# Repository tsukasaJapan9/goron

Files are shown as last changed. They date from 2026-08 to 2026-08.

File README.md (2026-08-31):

# goron — 2軸クランク脚ロボット

胴体＋左右独立2脚（360°連続回転）で、起き上がり・移動・横転・ジャンプを
強化学習で獲得させるプロジェクト。MuJoCo でのシミュレーションと Sim2Real を前提とする。

参考: [poco](https://homemadegarbage.com/rl13)（2軸シリアルアーム型）。本機はシリアル
チェーンではなく **胴体＋左右独立脚のパラレル構造**で、脚が連続回転する点が異なる。
脚を矢状面で連続回転させる構成は [RHex](https://en.wikipedia.org/wiki/RHex) 系
（回転するCレッグ）の最小構成にあたる。

## 機体構成

```
        torso  (M5Stack + バッテリー, free joint)
       /                              \
   hip_left (hinge, axis = Y)   hip_right (hinge, axis = Y)
   360°連続回転                  360°連続回転
```

脚は胴体の左右（±Y）に取り付くが、**振れる向きは前後（矢状面）**。ヒンジ軸が
胴体の左右方向(Y)に平行なので、両脚がオールのように前後に回り続ける。

この選択が設計全体を規定する:

- 両脚を揃えて回すと**ピッチ**トルクが出る。起き上がりは横転ではなく
  **前転／後転（宙返り）**になる。
- 難易度を決める胴体寸法は `torso_width` ではなく **`torso_len` (X)**。
  胴体は前後の端（x = ±27 mm）を支点として越えていく必要がある。
- 左右のミラー関係が存在しない。両ヒップとも +Y 軸まわりに同じ向きに回るので、
  `ctrl = [+a, +a]` で同位相（ピッチ／ホップ）、`ctrl = [+a, -a]` で逆位相
  （ヨー／シザース）。
- ヒップは**胴体より外側**（`hip_y_gap`）に出す必要がある。そうしないと脚が
  胴体を通過できず360°回転が成立しない。`leg_clears_torso` で検査している。

## 実機構成

| 部品 | 型番 | 諸元 |
|---|---|---|
| サーボ×2 | Dynamixel **XL330-M288-T** | 288.4:1、停動 0.52 N·m / 無負荷 103 rpm (5V)、12bit絶対エンコーダ、18 g |
| コントローラ | **M5Stack Core** 系 | 54×54×16 mm、6軸IMU内蔵 |

合計約 151 g。サーボは **Extended Position Control Mode（±256回転）** で駆動する。
このモードだけが「360°連続回転」と「絶対角度フィードバック」を同時に成立させる。

### 設計上の落とし穴（実装で踏んだもの）

**XL330のケース厚(26 mm)は M5Stack(16 mm)より厚い。** サーボを胴体の中央高さに
付けると、ケースが腹面より 5 mm 下に突き出し、ロボットは腹ではなく**サーボケースの上に
乗って静止する**。この状態では「腹が接地」というゴール条件が原理的に達成できず、
ゴール到達可能なクランク角は 24通り中 2通りしかなかった。サーボを上面側
(`hip_z_frac=1.0`) に寄せると 19/24 に改善する。`servo_clears_belly` で検査し、
`train.py` は違反する設定を起動時に拒否する。

## ゴール姿勢の定義（パターンA:「伏せ」）

`SelfRight` タスクは次の3条件が `hold_steps`（既定 25 step = 0.5 s）連続で成立したら成功:

1. 胴体の上向き軸が鉛直から `prone_tilt`（既定 25°）以内
2. **胴体の箱が床に接触している**（脚やサーボで突っ張っているのではない）
3. 角速度 |ω| が `settle_omega`（既定 3.0 rad/s）未満

2番目の接触条件が本質的。これがないと「脚で突っ張って斜めに静止」が成功扱いになる。
1番目は「横倒し／エッジ立ち」を排除する。脚は連続回転するので、伏せるにはクランクを
上向きに畳む必要があり、自然に「脚をたたむ」動作が要求される。

## 観測と行動（実機で取れる量だけ）

観測 14次元 — すべて M5Stack の6軸IMU と XL330 の TTL フィードバックから得られる:

| index | 内容 | 実機での取得元 |
|---|---|---|
| 0:3 | 重力方向（胴体座標系） | IMU 姿勢フィルタ / 加速度計 |
| 3:6 | 角速度 (rad/s) | ジャイロ |
| 6:10 | 各クランク角の sin/cos | XL330 絶対エンコーダ |
| 10:12 | クランク角速度（正規化） | XL330 Present Velocity |
| 12:14 | サーボトルク（正規化） | XL330 Present Current |

クランク角を生の角度ではなく **sin/cos** で入れているのは、関節が回り続けるため。
生角度だと1周ごとに不連続になり、値も無限に増える。

意図的に**含めない**もの: 胴体の位置とヨー角。実機で測れないし、どのタスクにも不要。
ヨー・並進・1回転ぶんのラップに対する観測の不変性はテストで担保している。

行動 2次元 `[-1, 1]`: Extended Position 目標角の**増分**。行動が飽和したとき
ちょうどサーボの無負荷速度になるようスケールしてある。さらに目標角は実測角から
`max_lead`（既定 0.5 rad）以内に制限される — これがないと脚が引っかかったときに
目標角が無限に先走り（ワインドアップ）、復帰に数秒かかる。実機でも必要なガード。

制御周期 50 Hz（物理 500 Hz、`frame_skip=10`）。

## タスク

ハードウェアは固定で、目的だけ差し替える。`Task` が持つのは
`reset()` / `reward()` / `terminated()` の3つだけで、観測・サーボモデル・接触判定は
`GoronEnv` 側にある。

| タスク | 内容 | 状態 |
|---|---|---|
| `selfright` | 仰向け → 伏せ | 調整済み |
| `forward` | 進行方向へ移動（RHex的なパドリング） | 初版 |
| `roll` | 横方向へ転がり続ける | 初版・意図的に難しい（矢状クランクはロールを直接作れない） |
| `jump` | 全体を浮かせる | 初版 |

`forward` / `roll` / `jump` は報酬項を素直に書いた初版で、ここから詰めるのが次の作業。

## セットアップと使い方

```bash
uv sync
uv run pytest tests/ -q

# MJCF を models/ に書き出す（閲覧用。学習側はこのファイルを読まない）
uv run python -m goron.model
uv run python -m mujoco.viewer --mjcf=models/goron_sagittal_bar.xml

# 設計解析: 越えるべき傾斜角と、開ループでの成功率
uv run python -m scripts.feasibility

# 設計スイープ: 脚形状・ヒップ位置ごとの成功率
uv run python -m scripts.basin

# 学習済み方策がどこで壊れるかを1軸ずつ探る
uv run python -m scripts.stress --run runs/selfright

# 学習
uv run python -m goron.train --task selfright --timesteps 2000000
uv run python -m goron.train --task forward --leg-shape c_leg

# 評価 + 動画
uv run python -m goron.eval --run runs/selfright --episodes 50 --video sr.mp4
```

## RL の前にやる設計解析

`scripts/feasibility.py` と `scripts/basin.py` は、**報酬設計をいじる前に機体形状が
解ける形になっているかを確認する**ためのもの。

- `flip_ladder()` — 胴体断面を「角で転がる長方形」とみなして、
  伏せ(0°) → エッジ立ち(90°) → 仰向け(180°) の間の不安定平衡点を出す。
  現行形状では仰向けから脱出するのに **106.5° を下回る**必要がある。
- `basin.py` — ランダムな開ループ行動列のうち何%がタスクのゴール判定を満たすかを測る。

**成功率**を見るのが重要で、「1回でも成功したか」では意味がない。開発中、可動域を
制限していた旧設計で見つけた唯一の成功シーケンスは、初期速度に 1e-4 rad/s の
ノイズを乗せただけで 0/10 に崩壊した。接触が支配的な系ではカオス的な"まぐれ当たり"が
出るので、方策が再現できる幅のある解でなければ意味がない。

参考値（既定形状、`selfright`）:

| 方策 | 結果 |
|---|---|
| 無動作 | 最終 tilt 155.6°（起き上がれない） |
| ランダム行動（毎ステップ） | 0/60 成功 |
| ランダム開ループ（0.4秒保持の区分定数） | 34.3% 成功 |

無動作では復帰せず、区分定数のランダム行動には広い成功領域がある — PPO にとって
適切な難易度。

## 学習結果（selfright, bar脚 50mm）

PPO 2M ステップ。**評価100エピソードで成功率100%、所要 0.8 秒**（うち 0.5 秒は
必須の保持時間なので、実際の起き上がり動作は約 0.3 秒）。20k ステップ時点で既に
100% に達し、以降 2M まで一度も崩れない。

学習した戦略は**クランク0.34回転（約124°）の単発の押し起こし**で、360°連続回転を
使い切ってはいない。起き上がりだけなら130°程度の可動域で足りる、ということでもある。

### 報酬ハッキングの記録

最初の実装では、成功でエピソードが終了する一方で成功ボーナスが定額 +100 だった。
ゴールに留まれば 3.0/step × 残り約380step ≈ 1150 得られるので、**サボる方が10倍
儲かる**。PPO は正しくこれを最適化し、伏せ姿勢に到達した上で1〜4ステップごとに
意図的にゴール条件を壊し続けた:

```
at_goal: 000000000000000111111110101110101111010111001110101111010111...
連続長:  [8, 1, 3, 1, 4, 1, 3, 3, 1, 4, ...]   ← 成功には連続25が必要
報酬 193 → 1006 に増加、成功率 100% → 0% に低下
```

修正は成功時に**残りエピソード分を払い出す**こと。これで留まる価値と等しくなり、
労力と時間ペナルティの分だけ早く終える方が厳密に有利になる。
`test_success_is_never_worth_less_than_loitering_at_the_goal` が回帰を防いでいる。

### 頑健性（`scripts/stress.py`）

1軸ずつ壊れるまで振った結果。ドメインランダム化なしで学習した方策を使用。

| 軸 | 破綻点 | 公称値との比 |
|---|---|---|
| 床摩擦 | μ=0 でも 100% | 効かない |
| **サーボトルク** | 0.05 N·m で 60%、0.03 N·m で 0% | **約10倍の余裕**（0.52 N·m） |
| 総質量 | ×16 で 100%、×24 で 84% | 16倍の余裕 |
| ギヤ減衰 | ×16 で 100%、×32 で 80% | 16倍の余裕 |
| 観測ノイズ | σ=0.8 でも 100% | — |

ドメインランダム化あり/なしの評価はどちらも100%だった。ランダム化幅（トルク±20%等）が
破綻点から桁で離れているため差が出ない。**この課題はトルク臨界ではない**ので、
サーボモデルの誤差が Sim2Real を壊す心配は小さい。

観測を殺すと成功率が落ちる（ゼロ固定 40%、ランダム 44%、正常 100%）ので、
方策は開ループではなく観測を実際に使っている。それでも大きなノイズに耐えるのは、
ノイズが乗っても信号が期待値として残るため。

## ファイル

| ファイル | 内容 |
|---|---|
| [goron/model.py](goron/model.py) | `RobotParams` と MJCF 生成。全寸法・サーボ諸元がパラメトリック |
| [goron/env.py](goron/env.py) | `GoronEnv`：観測・行動・サーボモデル・接触判定 |
| [goron/tasks.py](goron/tasks.py) | タスク定義（selfright / forward / roll / jump） |
| [goron/train.py](goron/train.py) | SB3 PPO の学習ループ |
| [goron/eval.py](goron/eval.py) | 成功率の評価と動画出力 |
| [scripts/feasibility.py](scripts/feasibility.py) | 傾斜ラダーと開ループ探索 |
| [scripts/basin.py](scripts/basin.py) | 設計スイープ（成功率ベース） |
| [scripts/stress.py](scripts/stress.py) | 学習済み方策の破綻点探索（Sim2Real マージン） |
| [tests/test_env.py](tests/test_env.py) | 静かに学習を壊す種類のミスを検出するテスト |
| [handbook/index.html](handbook/index.html) | モデル作成→強化学習→実機デプロイの入門教材。実測値と失敗例つき |

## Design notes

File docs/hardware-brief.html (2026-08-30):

シミュレーション検証済 / 設計入力

# 2軸クランク脚ロボット 設計ブリーフ

MuJoCo + PPO で起き上がり・移動を検証した結果から、筐体設計に効く制約と実測荷重をまとめたもの。数値はすべてシミュレーション実測値。

脚形状

C脚

起き上がり

100% / 0.8 s

転がり移動

0.44 m/s

非回転移動

0.15 m/s

トルク余裕

7–10×

## 守らないと成立しない制約

以下は「あった方がよい」ではなく、外すとロボットが機能しなくなる項目。いずれも実測で確認している。

クリアランス

### サーボケースを腹面より下に出さない

XL330 のケース厚 26 mm は M5Stack の 16 mm より厚い。胴体の中央高さに取り付けると、ケースが腹面より 5 mm 下に突き出し、ロボットは腹ではなくサーボケースの上に乗って静止する。この状態では「腹を接地させる」動作が原理的に成立しない。

開ループ起き上がり成功率 — 上面マウント 47.0% / 中央マウント 0.75%。同一形状で取付高さを変えただけの差。ゴール到達可能なクランク角も 2/24 → 19/24 に変化する。

可動域

### ヒップ軸を筐体側面より外側に出す

脚が筐体の外側を通過できなければ 360° 回転が物理的に成立しない。ヒップ軸の左右オフセットは筐体半幅 + 脚半径より大きく取る。現行モデルでは側壁から 12 mm 外側。

検査式 hip_y > torso_width/2 + leg_radius をコード側に実装済（leg_clears_torso）。24 姿勢すべてで自己干渉ゼロを回帰テストで確認している。

制御モード

### Extended Position Control Mode を使う

通常の Position Control Mode（0–360°）では連続回転ができない。Extended Position Control Mode（±256 回転）だけが360° 連続回転と絶対角度フィードバックを同時に成立させる。観測に脚の位相が入ることが学習の前提になっている。

観測を殺すと起き上がり成功率は 100% → 40%（ゼロ固定）/ 44%（ランダム）に低下。方策は開ループではなく、実際に位相情報を使っている。

## 脚形状の選定

起き上がりは両者同等、移動は C脚が 2.4 倍。C脚に一本化してよい。

項目 | バー脚 | C脚 | 判定
起き上がり成功率 | 100% | 100% | 同等
起き上がり所要時間 | 0.8 s | 0.8 s | 同等
転がり移動 | 0.18 m/s | 0.44 m/s | C脚 2.4×
非回転移動 | — | 0.15 m/s | C脚のみ検証
車高変動（1回転あたり） | 40 mm | 17 mm | C脚が滑らか
トルク破綻点 | 0.03–0.05 N·m | 0.05–0.07 N·m | 実用差なし

開ループ比較では逆にバーが有利（成功率 47% 対 26%、押し上げ量 48 mm 対 25 mm）だったが、学習を入れると逆転した。C脚は接地点が弧の上を移動するため接地時間が長く、押す方向を制御できる。開ループ比較だけで脚形状を決めると誤る。

## 設計荷重

最悪ケース（連続宙返り、学習済み方策）で測定した接触荷重。

荷重 | バー脚 | C脚 | 設計上の意味
最大接触力 | 30.7 N | 43.7 N | 自重の 21–29 倍
ヒップ軸への衝撃トルク | 0.59 N·m | 0.69 N·m | 停動トルクの 1.1–1.3 倍
胴体の最高到達高さ | 34 mm | 41 mm | 低い転がり。飛翔はしない
着地速度 | 0.52 m/s | 0.47 m/s | —

この数値は過小評価。 MuJoCo の接触は時定数 5 ms の柔らかい設定で、実機の樹脂対硬質床は 1 ms 以下。同じ力積でもピーク力は実機の方が高く出る。信頼できるのは力積の方。

最も弱いのは XL330 の樹脂ギヤ。 脚がホーンに直結しているため、着地衝撃がそのままギヤ列に入る。12 秒で 40 回以上の半回転＝数千回の繰り返しになるので、1 回耐えられても摩耗・欠けが問題になる。

- 脚を柔軟素材でプリント、または C脚にばね区間を設ける — 最も効く対策
- 足先に TPU パッドを付けてピーク力を落とす
- 報酬に衝撃ペナルティを入れて再学習すれば、方策側から歩容を穏やかにできる（未実施）

シミュレーションの C脚は剛体。 実機でばねとして作れば衝撃を吸収するので、上の C脚の荷重値は悲観側の見積もり。RHex が C脚を採用する理由の半分（弾性によるドライブトレイン保護）はまだモデル化できていない。

## 気にしなくてよい項目

1軸ずつ破綻するまで振った結果。設計の制約にならないことが確認できた項目。

軸 | 破綻点 | 公称値との比
床摩擦 | μ = 0 でも 100% | 影響なし。滑る床でも動作する
サーボトルク | 0.03–0.07 N·m | 公称 0.52 N·m に対し 7–10 倍の余裕
総質量 | ×16 で 100% | 筐体が重くなっても余裕がある
ギヤ減衰 | ×16 で 100% | 個体差・経年劣化を吸収できる
観測ノイズ | σ = 0.8 でも 100% | IMU 品質は制約にならない

ドメインランダム化あり／なしの評価がどちらも 100% だったのは、ランダム化幅が破綻点から桁で離れているため。この課題はトルク臨界ではないので、サーボモデルの誤差が Sim2Real を壊す心配は小さい。

## 制御インターフェース

実機ファームウェアが満たすべき仕様。観測はすべて M5Stack の 6 軸 IMU と XL330 のフィードバックから取得できる量のみで構成してある。

制御周期

50 Hz（物理 500 Hz / frame_skip 10）

行動

目標角の増分 2 次元。飽和時に無負荷速度 10.8 rad/s 相当

ワインドアップ防止

目標角を実測角の ±0.5 rad 以内に制限（必須）

観測

14 次元 — 重力方向 3 / ジャイロ 3 / クランク角 sin·cos 4 / 角速度 2 / 電流 2

クランク角の扱い

生角度ではなく sin/cos。連続回転で不連続と発散を避けるため

使わない量

胴体位置・ヨー角・関節実測角以外の内部状態

## 筐体寸法の決め方

3 軸のうち効くのは高さだけ。しかも効き方が直感と逆なので、ここは意識的に決める価値がある。

背が高い筐体ほど起き上がりやすい。 薄く作りたくなるところだが逆効果。背が高いほど仰向け姿勢が不安定になり、脱出に必要な回転角が小さくなる。高さ 16 mm → 40 mm で開ループ成功率が 約 4 倍になる。

C脚・幅 72 mm・質量 214 g 固定。開ループ起き上がり成功率（250 試行）
高さ (Z) | 前後長 54 | 60 | 70 | 80 | 90
40 mm | 62.4% | 68.8% | 73.6% | 70.8% | 32.4%
32 mm | 46.0% | 49.2% | 53.2% | 55.6% | 52.8%
24 mm | 28.8% | 32.0% | 37.6% | 38.8% | 36.8%
16 mm | 18.0% | 17.2% | 20.0% | 22.8% | 19.6%

- 高さは 32 mm 以上、可能なら 40 mm。部品を積み上げれば自然に届く（M5Stack 16 + サーボ 26 で既に 26 mm 以上）
- 前後長は 54–80 mm ならほぼ自由。同じ高さの中では差が小さい。ただし 90 mm は落ちるので上限とみなす
- 幅は 72 mm 前後で事実上固定。XL330 を軸方向（Y）に 2 個並べると 68 mm 必要で、ここに選択の余地はない

この成功率は合否ではなく余裕の指標。学習を入れれば開ループ 47% の構成でも 100% に達している。低い数字でも動くが、余裕が小さいほど実機での誤差に弱い。

サーボを筐体内に収めるなら制約 1（ケース突出）は自動的に解決する。ただし出力軸が側壁より外に出ていることと、筐体内でのヒップ軸の高さは別途決める必要がある。寸法が決まったら RobotParams の torso_len / torso_width / torso_height / board_mass を書き換えて scripts/basin.py を再実行すれば、同じ指標で比較できる。

## 未検証

- 方向制御 — 現在の移動報酬は「スタート地点から遠ざかる」だけで、行き先を指定できない。操縦可能にするには目標方位を観測に追加する必要がある
- 横転・ジャンプ — タスクは実装済みだが未学習
- 脚の弾性 — C脚は剛体としてモデル化。ばね特性は未反映
- 実機でのサーボ応答遅延・通信遅延 — モデルに入っていない

数値はすべて MuJoCo シミュレーションの実測値（PPO 学習済み方策、評価 25–100 エピソード）。 再現手順とコードはリポジトリの README を参照。

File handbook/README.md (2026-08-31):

# Sim2Real 実践帳

`index.html` は単体で完結した教材です。ブラウザで開くだけで読めます（依存なし、
フォントのみ Google Fonts から取得）。

    xdg-open handbook/index.html

MuJoCo でのモデル作成から強化学習、実機同定、M5Stack へのデプロイまでを、この
リポジトリで実際に測った数値と、実際に踏んだ失敗で追いかけます。図はすべて実データ
から起こしたもので、ステップ応答は `scripts/export_policy.py` が扱うのと同じ run、
摩擦スイープは `scripts/friction_test.py` の実測値です。

数値を更新したときは、本文の該当箇所も直してください。教材の価値は数字が本物である
ことなので、モデルだけ更新して本文が古いままになるのがいちばん困ります。

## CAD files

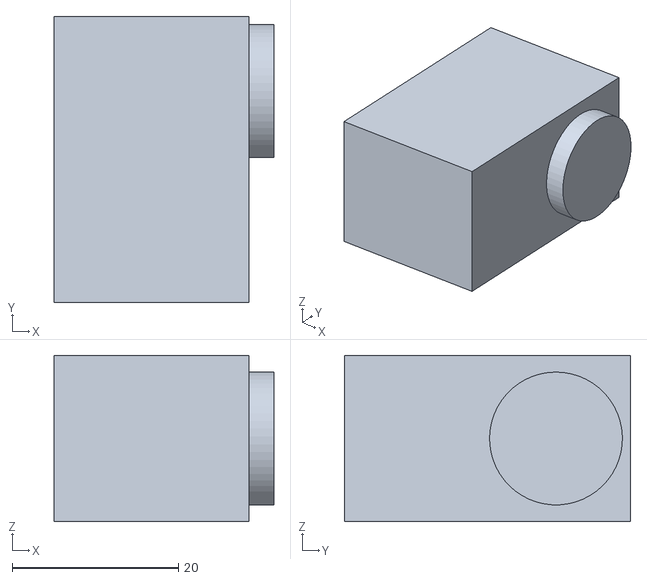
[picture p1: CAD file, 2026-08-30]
hardware/stl/servo_right.stl
26.5 x 34.5 x 20.0

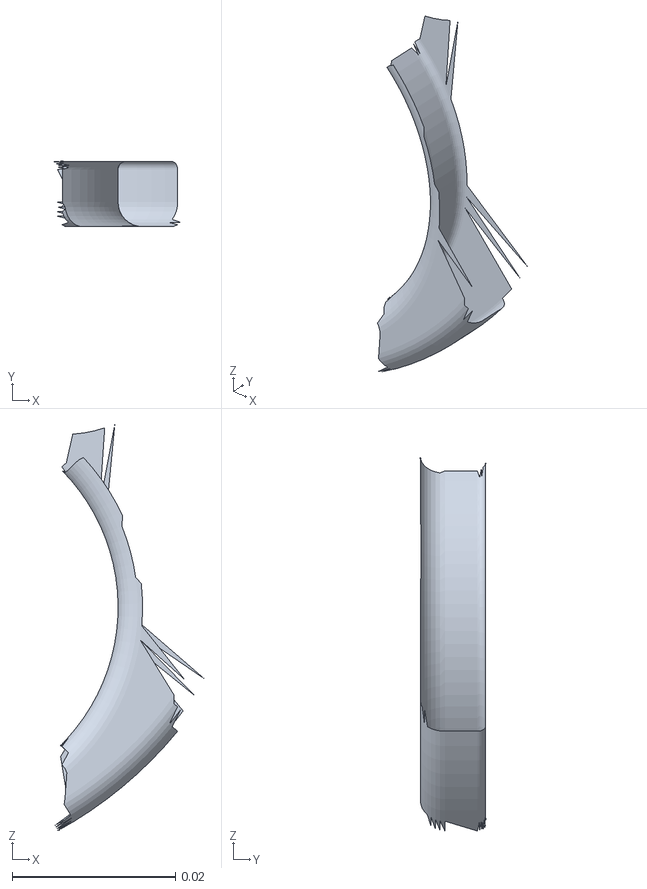
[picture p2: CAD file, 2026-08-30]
hardware/stl/wedges/wedge_18.stl
0.0184 x 0.008 x 0.0499

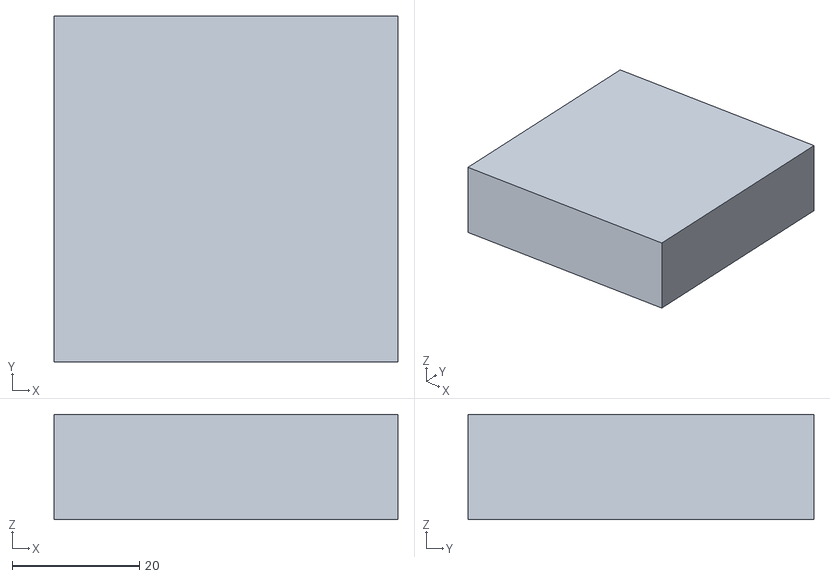
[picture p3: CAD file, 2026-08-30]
hardware/stl/m5stack.stl
54.0 x 54.3 x 16.5

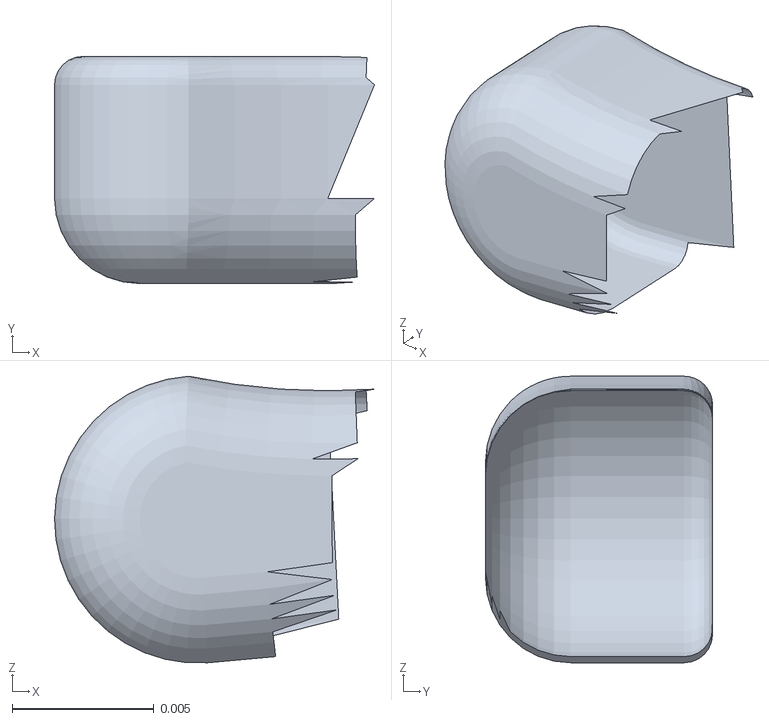
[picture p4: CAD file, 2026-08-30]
hardware/stl/wedges/wedge_16.stl
0.0113 x 0.008 x 0.0101

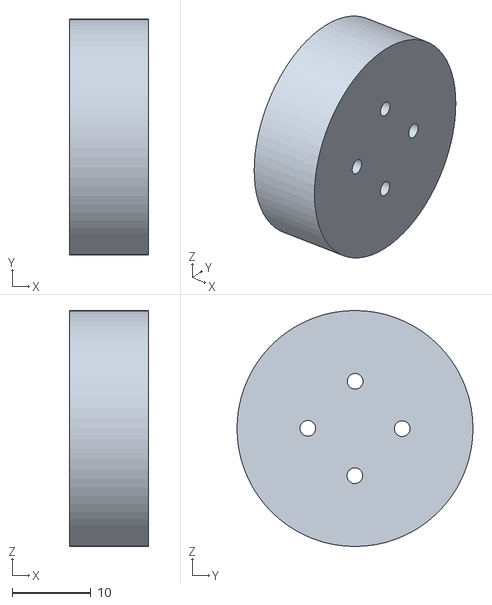
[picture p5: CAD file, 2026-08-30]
hardware/stl/servo_joint_left.stl
10.0 x 30.0 x 30.0

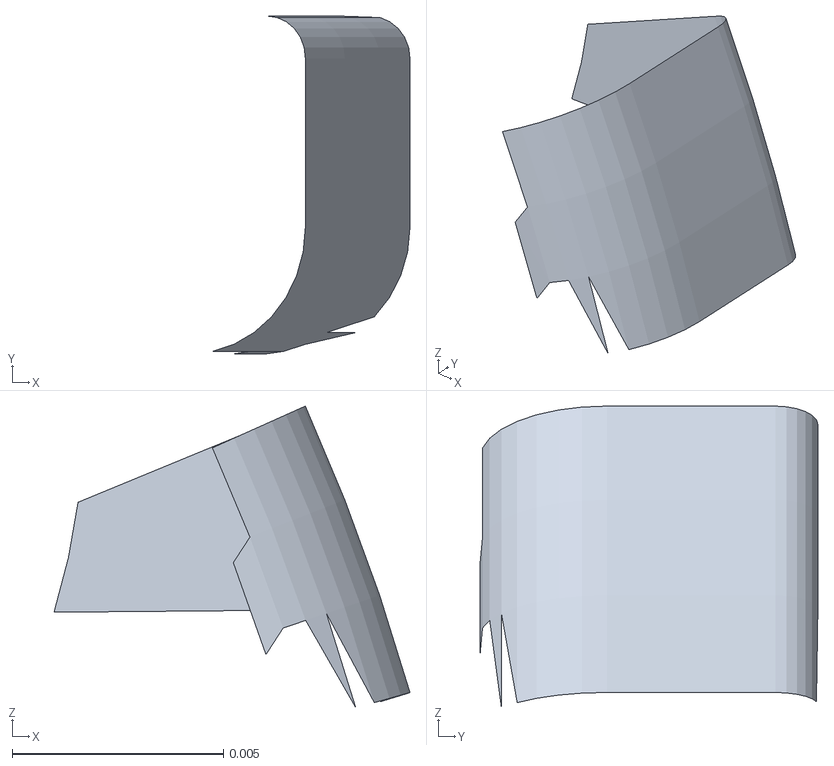
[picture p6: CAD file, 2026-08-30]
hardware/stl/wedges/wedge_23.stl
0.00843 x 0.008 x 0.00715

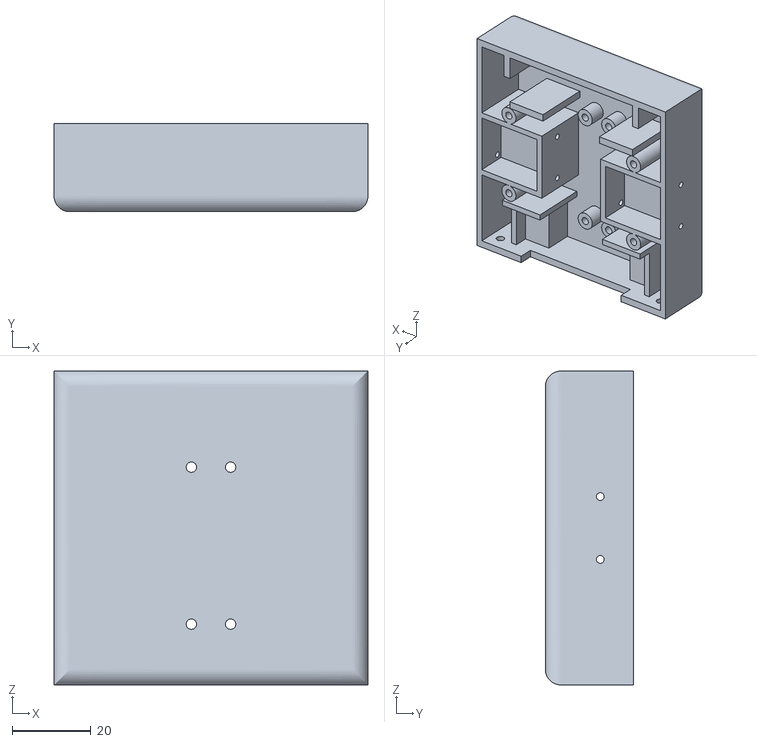
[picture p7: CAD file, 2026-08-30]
hardware/stl/body_bottom.stl
80.0 x 22.5 x 80.0

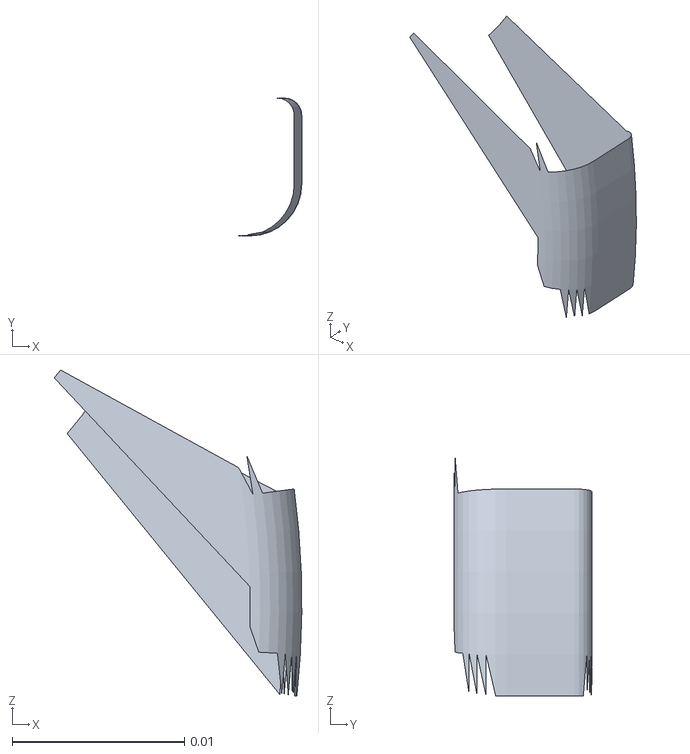
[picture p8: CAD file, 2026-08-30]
hardware/stl/wedges/wedge_21.stl
0.0144 x 0.008 x 0.0189

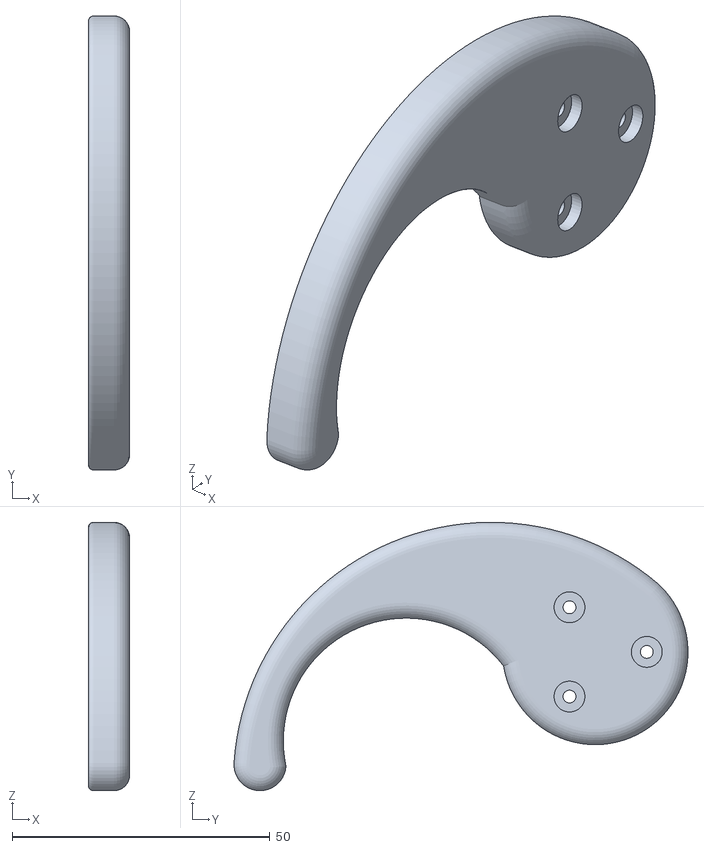
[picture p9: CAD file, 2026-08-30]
hardware/stl/leg_right.stl
8.00 x 88.1 x 52.1

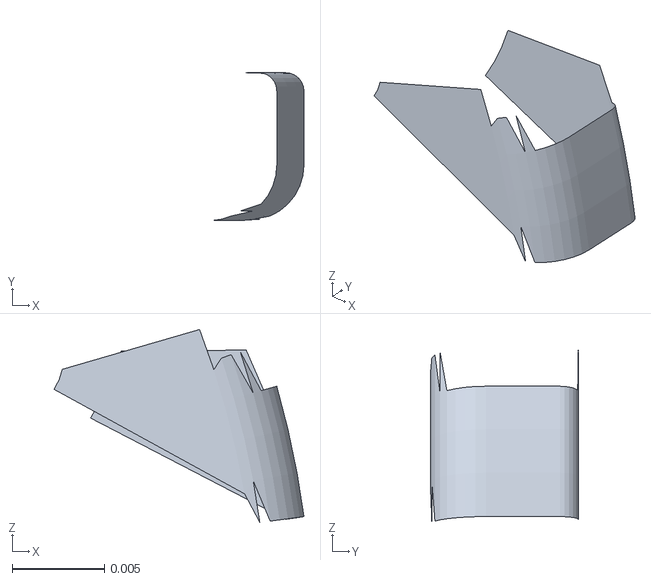
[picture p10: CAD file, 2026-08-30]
hardware/stl/wedges/wedge_22.stl
0.0136 x 0.008 x 0.0105

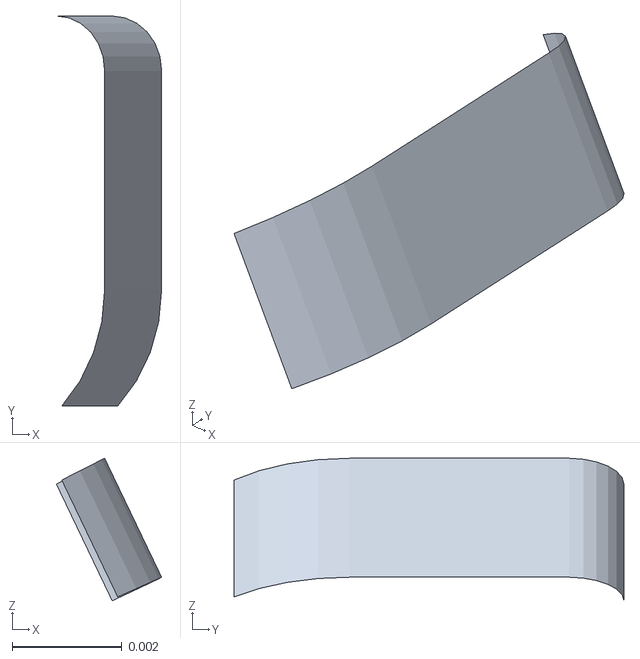
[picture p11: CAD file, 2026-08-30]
hardware/stl/wedges/wedge_00.stl
0.00192 x 0.00712 x 0.0026

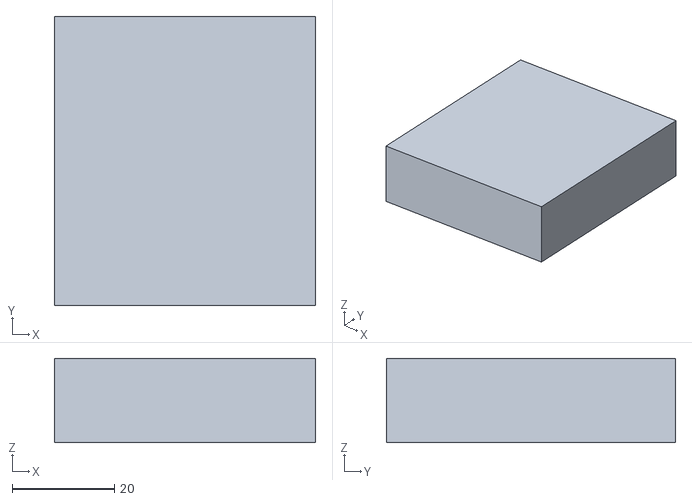
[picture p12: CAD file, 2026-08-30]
hardware/stl/bat.stl
51.0 x 56.5 x 16.5

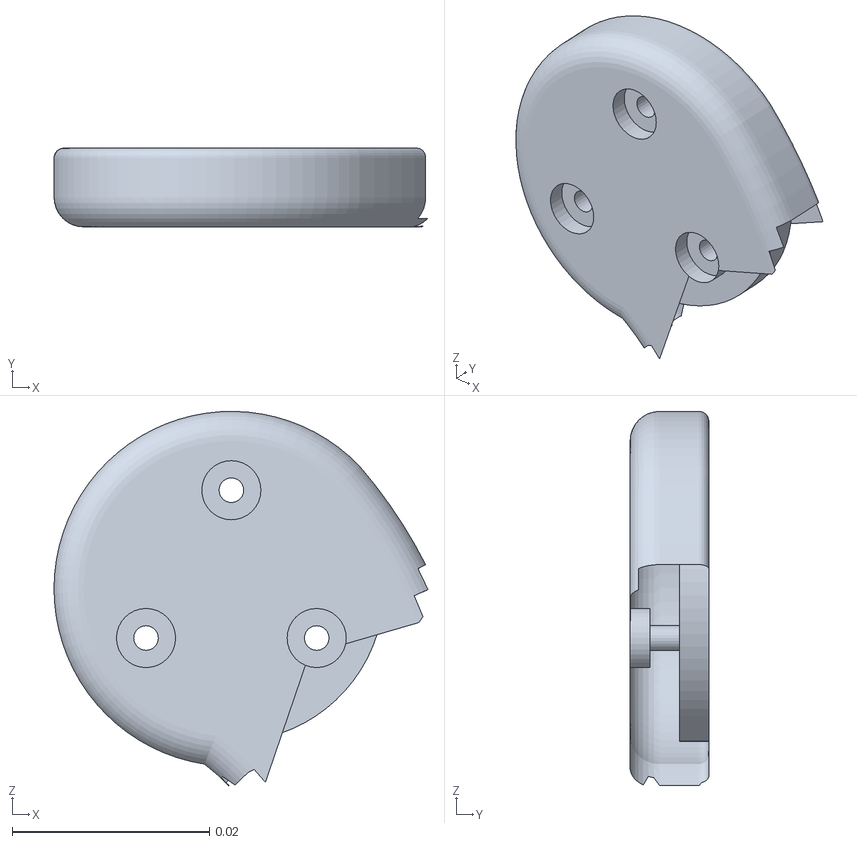
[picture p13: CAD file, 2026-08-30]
hardware/stl/wedges/hub.stl
0.038 x 0.008 x 0.038

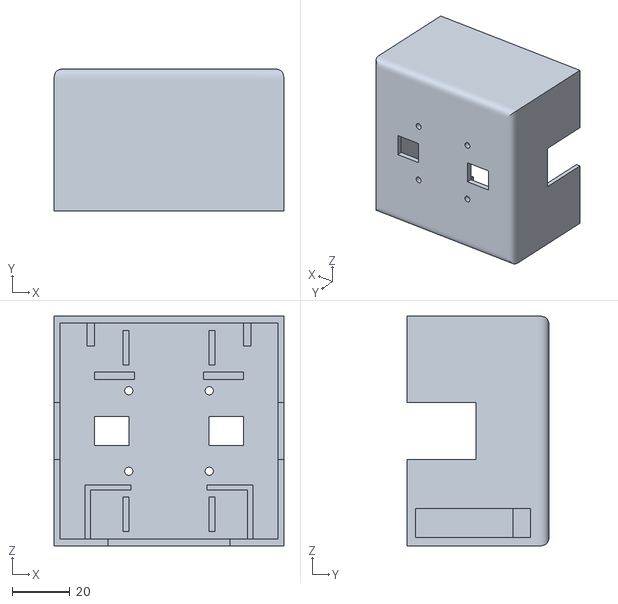
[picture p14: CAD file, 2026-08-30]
hardware/stl/body_upper.stl
80.0 x 49.5 x 80.0

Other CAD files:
hardware/stl/servo_left.stl
hardware/stl/wedges/wedge_19.stl
hardware/stl/leg_left.stl
hardware/stl/wedges/wedge_17.stl
hardware/stl/all.stl
hardware/stl/servo_joint_right.stl
hardware/stl/wedges/wedge_20.stl

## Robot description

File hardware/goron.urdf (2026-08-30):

<?xml version="1.0"?>
<robot name="goron">
  <mujoco>
    <compiler meshdir="stl/" discardvisual="false" balanceinertia="true"/>
  </mujoco>
  <link name="base_link">
    <inertial>
      <origin xyz="-0.000237 0.030193 -0.000854"/>
      <mass value="0.28590"/>
      <inertia ixx="3.2346e-04" ixy="4.1388e-07" ixz="-2.2208e-07" iyy="3.4242e-04" iyz="1.3147e-05" izz="2.6914e-04"/>
    </inertial>
    <visual><origin xyz="0 0 0"/><geometry><mesh filename="body_bottom.stl" scale="0.001 0.001 0.001"/></geometry></visual>
    <visual><origin xyz="0 0 0"/><geometry><mesh filename="body_upper.stl" scale="0.001 0.001 0.001"/></geometry></visual>
    <visual><origin xyz="0 0 0"/><geometry><mesh filename="m5stack.stl" scale="0.001 0.001 0.001"/></geometry></visual>
    <visual><origin xyz="0 0 0"/><geometry><mesh filename="bat.stl" scale="0.001 0.001 0.001"/></geometry></visual>
    <visual><origin xyz="0 0 0"/><geometry><mesh filename="servo_left.stl" scale="0.001 0.001 0.001"/></geometry></visual>
    <visual><origin xyz="0 0 0"/><geometry><mesh filename="servo_right.stl" scale="0.001 0.001 0.001"/></geometry></visual>
  </link>
  <joint name="hip_left" type="continuous">
    <parent link="base_link"/>
    <child link="leg_left"/>
    <origin xyz="0 0.035000 0.000000"/>
    <axis xyz="1 0 0"/>
    <limit effort="0.52" velocity="10.79"/>
    <dynamics damping="0.0482"/>
  </joint>
  <link name="leg_left">
    <inertial>
      <origin xyz="-0.050440 -0.016402 0.003452"/>
      <mass value="0.00900"/>
      <inertia ixx="6.0563e-06" ixy="-2.1045e-07" ixz="4.7400e-08" iyy="1.2843e-06" iyz="-9.3787e-08" izz="5.0326e-06"/>
    </inertial>
    <visual><origin xyz="0 -0.035000 -0.000000"/><geometry><mesh filename="leg_left.stl" scale="0.001 0.001 0.001"/></geometry></visual>
    <visual><origin xyz="0 -0.035000 -0.000000"/><geometry><mesh filename="servo_joint_left.stl" scale="0.001 0.001 0.001"/></geometry></visual>
  </link>
  <joint name="hip_right" type="continuous">
    <parent link="base_link"/>
    <child link="leg_right"/>
    <origin xyz="0 0.035000 0.000000"/>
    <axis xyz="1 0 0"/>
    <limit effort="0.52" velocity="10.79"/>
    <dynamics damping="0.0482"/>
  </joint>
  <link name="leg_right">
    <inertial>
      <origin xyz="0.050430 -0.016381 0.003448"/>
      <mass value="0.00900"/>
      <inertia ixx="6.0522e-06" ixy="2.1178e-07" ixz="-4.7676e-08" iyy="1.2839e-06" iyz="-9.3014e-08" izz="5.0303e-06"/>
    </inertial>
    <visual><origin xyz="0 -0.035000 -0.000000"/><geometry><mesh filename="leg_right.stl" scale="0.001 0.001 0.001"/></geometry></visual>
    <visual><origin xyz="0 -0.035000 -0.000000"/><geometry><mesh filename="servo_joint_right.stl" scale="0.001 0.001 0.001"/></geometry></visual>
  </link>
</robot>

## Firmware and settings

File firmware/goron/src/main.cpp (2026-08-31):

// goron フェイス - Core2 の LCD に Cozmo 風の目を表示する
//
// References:
// https://docs.m5stack.com/en/core/core2
// https://github.com/m5stack/M5Unified
// https://github.com/lovyan03/LovyanGFX
//
// 黒背景に青い角丸四角の目を2つ描き、まばたき・視線移動を自律的に再生する。
// 全画面スプライト(M5Canvas)に描いてから一括転送することでちらつきを防ぐ。
//
// 移植元 (ai_robotics/firmware/stackchan) は上下まぶたで目を削って12種類の表情を
// 作っていたが、ここでは normal（まばたき・視線のゆらぎ・呼吸の上下動だけ）に絞る。
//
// 脚: DYNAMIXEL XL330-M288-T ×2（Extended Position Control Mode）
//   PORT.A に TTL インターフェース基板を介して接続。
//   基板が送受信を自動で切り替えるため DIR ピンの制御は不要。
//   起動時にクランクを1周回してから 0度 に戻し、配線・通信と原点を同時に確認する。

#include <M5Unified.h>
#include <Dynamixel2Arduino.h>
#include <Preferences.h>
#include <math.h>

#include "imu_map.h"   // scripts/make_imu_header.py が hardware/imu_map.json から生成
#include GORON_POLICY  // scripts/export_policy.py が学習結果から生成

// --- 目のデザインパラメータ（見た目を調整する箇所） ---

static const int SCREEN_W = 320;
static const int SCREEN_H = 240;
static const int EYE_W    = 78;   // 目の幅
static const int EYE_H    = 96;   // 目の高さ（開いた状態）
static const int EYE_R    = 24;   // 角丸半径
static const int EYE_GAP  = 44;   // 左右の目の隙間
static const int EYE_CY   = 90;   // 目の中心Y（顔として見えるよう画面中央より上に置く）

static const uint16_t COLOR_EYE   = 0x05FF;  // 明るいシアン (#00BFFF 相当)
static const uint16_t COLOR_BG    = TFT_BLACK;
static const uint16_t COLOR_LABEL = 0x4208;  // 状態表示。目より目立たない暗いグレー
static const int      STATUS_MARGIN = 8;     // 状態表示と画面下端の間隔

// --- アニメーションパラメータ ---

static const uint32_t FRAME_MS     = 33;   // 約30fps
static const uint32_t BLINK_MS     = 150;  // まばたき1回にかける時間
static const uint32_t BLINK_MIN_MS = 2000; // まばたきの間隔（ランダム）
static const uint32_t BLINK_MAX_MS = 6000;
static const float    BLINK_OPEN   = 0.05f; // 閉じきったときの開き具合

static const uint32_t SACCADE_MS     = 120;  // 視線移動にかける時間
static const uint32_t SACCADE_MIN_MS = 1000; // 視線移動の間隔（ランダム）
static const uint32_t SACCADE_MAX_MS = 4000;
static const int      GAZE_RANGE_X   = 10;   // 視線オフセットの振れ幅
static const int      GAZE_RANGE_Y   = 8;

static const float    DRIFT_PX        = 2.0f;   // 呼吸のような緩やかな上下動
static const uint32_t DRIFT_PERIOD_MS = 4000;

// --- 脚（DYNAMIXEL XL330-M288-T）---

// PORT.A（G32/G33）。基板のサンプルは RX=32/TX=33 だが、実機はこの向きでしか応答しない
static const int      DXL_RX_PIN   = 33;
static const int      DXL_TX_PIN   = 32;
static const float    DXL_PROTOCOL = 2.0f;
static const uint32_t DXL_BAUD     = 1000000;
// 実機をスキャンして確認した ID。並び順が左右を決める（先頭が左脚）。
// 観測 [sin(qL), sin(qR), cos(qL), cos(qR)] とテレメトリの並びがこれに従う。
//
// ここで言う「左」はモデルの +Y 側であって、見た目の左右ではない。モデルの +X は
// 画面と反対を向く（m5stack.stl は CAD Z -37.5..-21、CAD Z が sim の X）ので、
// 画面のある側を前だと思って数えると左右が入れ替わる。scripts/mirror で実機と
// 見比べて確定した並びがこれ。
static const uint8_t  DXL_IDS[]    = {1, 2};
static const uint8_t  DXL_COUNT    = sizeof(DXL_IDS) / sizeof(DXL_IDS[0]);
static const uint32_t DXL_SETTLE_MS  = 200;
static const uint8_t  DXL_PING_RETRY = 3;

// 名前は ControlTableItem の列挙子と衝突するので DXL_ を付ける
static const uint16_t DXL_PROFILE_ACC = 20;   // ×214.577 rev/min^2。急発進させない
static const uint16_t DXL_PROFILE_VEL = 100;  // ×0.229 rpm ≒ 23 rpm。ホームへ戻るときの速さ
static const float    HOME_DEG        = 90.0f;  // B ボタンで入れるクランク角（原点からの角度）

// C ボタンで較正するときに作る姿勢の、クランク角。
// 「胴体を床に伏せ、両脚の先端が床に触れる」姿勢。目分量の CAD 姿勢と違って
// 機械的に再現できるので原点の基準に向く。RobotParams.asbuilt() の寸法から
// 計算した値（ヒンジ高さ 37.4 mm、脚先半径 73.7 mm）。もう一方の交点 62.1 度は
// 腕の途中が当たるだけで先端は浮くため、基準にはならない。寸法を変えたら再計算する。
static const float    CALIB_POSE_DEG  = 279.6f;
static const char*    NVS_NAMESPACE   = "goron"; // 較正した原点の保存先

// --- 方策の実行 ---
//
// 観測・行動の規約はエクスポートしたヘッダの冒頭に書いてある。ここで守るべきは:
//   * 観測はシミュレータのボディ座標系。IMU は imu_map.h で回してから使う
//   * クランク角は較正した原点から。方策ごとの GORON_CRANK_ZERO_DEG を引く
//   * 行動は Extended Position 目標角の「増分」。実測角から GORON_MAX_LEAD 以内に
//     制限する（アンチワインドアップ。脚が引っかかったとき目標が無限に先走るのを防ぐ）
//   * プロファイル(台形加減速)は切る。入れると台形生成器の設定を追うことになり、
//     サーボ同定もこの条件で行っている
static const float GORON_NO_LOAD_SPEED = 10.79f;  // rad/s、観測の正規化に使う
static const float GORON_STALL_TORQUE  = 0.52f;   // N.m、同上
static const float DXL_SAT_CURRENT_MA  = 860.0f;  // 全開PWMで流れる電流の実測値
static const uint32_t POLICY_PERIOD_US = 1000000UL / GORON_CONTROL_HZ;

// --- テレメトリ（PC 側の scripts/mirror.py がこれを読んで MuJoCo に流す）---
static const uint32_t TELEM_MS = 50;  // 20Hz。目視で追う用途にはこれで足りる
// Aボタンで回すときの回転数（机から落とさない程度）。負 = 逆転
static const int      SPIN_RPM        = -20;
static const uint32_t BOOT_SHOW_MS    = 1000; // 起動メッセージを読む時間

// --- 状態 ---

static M5Canvas canvas(&M5.Display);

static uint32_t blinkAt  = 0;  // 次のまばたき開始時刻
static uint32_t blinkEnd = 0;  // まばたき終了時刻（過ぎていれば目は開いている）

static int      gazeX = 0, gazeY = 0;          // 現在の視線オフセット
static int      gazeFromX = 0, gazeFromY = 0;  // サッケードの始点
static int      gazeToX = 0, gazeToY = 0;      // サッケードの終点
static uint32_t gazeStart = 0;
static uint32_t gazeAt    = 0;  // 次のサッケード開始時刻

// --- 脚 ---

static Dynamixel2Arduino dxl;
using namespace ControlTableItem;

static uint8_t legIds[DXL_COUNT];
static uint8_t legCount = 0;
static bool    spinning = false;
static uint8_t legMode  = 0xFF;  // 現在の動作モード。0xFF = 未設定（最初は必ず書き込む）

// 制御ループは Core1 の専用タスクで回す。Core0 の顔の描画は PSRAM から
// 320x240 を転送するのに数十ms かかり、同じループに置くと 20ms の周期を守れない
static volatile bool policyRunning = false;
// 制御ループが読んだ値の写し。方策の実行中、テレメトリはこれを送る。
// テレメトリが自分でサーボを読むと Core0 と Core1 が同じ TTL バスを取り合って
// 通信が壊れるので、読むのは制御ループの1箇所だけにする
static volatile float lastRaw[DXL_COUNT], lastCrank[DXL_COUNT], lastImu[6];
static volatile uint32_t policyHz = 0;   // 実測の制御周波数
// 空回し。観測と方策の計算はするが目標角を送らない。IMU の軸・クランク角・
// 正規化・制御周期を、脚を動かさずに検証するため
static bool  policyDryRun = false;
static float policyTarget[DXL_COUNT];   // Extended Position の目標角[deg]（多回転のまま）
static float policyAction[GORON_ACT];   // 表示用
static uint32_t policyLateUs = 0;       // 周期に間に合わなかった最大の遅れ

static Preferences prefs;
static float legZero[DXL_COUNT] = {0.0f, 0.0f};  // CAD組立姿勢のサーボ角[deg]
static bool  calibrating = false;

// 角度差を (-180, 180] に畳む。どちら回りが近いかの判断に使う
static float wrapDeg(float d) {
    d = fmodf(d + 180.0f, 360.0f);
    if (d < 0.0f) d += 360.0f;
    return d - 180.0f;
}

// 較正した原点から見たクランク角 [0, 360)。
// XL330 は絶対エンコーダなので、再起動して多回転ぶんが失われても mod 360 で復元できる
static float crankDeg(uint8_t i, float present) {
    float d = fmodf(present - legZero[i], 360.0f);
    return (d < 0.0f) ? d + 360.0f : d;
}

static void loadZeros() {
    // 書き込み可で開く。読み出し専用だと初回（名前空間が無い）にエラーを吐く
    prefs.begin(NVS_NAMESPACE, false);
    for (uint8_t i = 0; i < DXL_COUNT; i++) {
        char key[8];
        snprintf(key, sizeof(key), "zero%u", DXL_IDS[i]);
        // 未較正のキーを getFloat すると Preferences がエラーを吐くので、先に有無を見る
        legZero[i] = prefs.isKey(key) ? prefs.getFloat(key) : 0.0f;
    }
    prefs.end();
    Serial.printf("crank zero: id%u=%.1f id%u=%.1f deg\n",
                  DXL_IDS[0], legZero[0], DXL_IDS[1], legZero[1]);
}

static void saveZeros() {
    prefs.begin(NVS_NAMESPACE, false);
    for (uint8_t i = 0; i < legCount; i++) {
        char key[8];
        snprintf(key, sizeof(key), "zero%u", legIds[i]);
        prefs.putFloat(key, legZero[i]);
    }
    prefs.end();
}

// 動作モードを揃える。切り替えにはトルクを落とす必要があるので、変わるときだけ触る
static void setMode(uint8_t mode) {
    if (legMode == mode) return;
    for (uint8_t i = 0; i < legCount; i++) {
        dxl.torqueOff(legIds[i]);
        dxl.setOperatingMode(legIds[i], mode);
        dxl.writeControlTableItem(PROFILE_VELOCITY, legIds[i], DXL_PROFILE_VEL);
        dxl.writeControlTableItem(PROFILE_ACCELERATION, legIds[i], DXL_PROFILE_ACC);
        dxl.torqueOn(legIds[i]);
    }
    legMode = mode;
}

// 起動時は通信の確認と速度モードの設定だけ。回すのは A ボタンから
static void setupLegs() {
    loadZeros();
    Serial2.begin(DXL_BAUD, SERIAL_8N1, DXL_RX_PIN, DXL_TX_PIN);
    dxl = Dynamixel2Arduino(Serial2);
    dxl.begin(DXL_BAUD);
    dxl.setPortProtocolVersion(DXL_PROTOCOL);
    delay(DXL_SETTLE_MS);  // 開いた直後は最初のパケットが落ちることがある

    for (uint8_t i = 0; i < DXL_COUNT; i++) {
        // 取りこぼしでモータを見失わないよう数回試す
        for (uint8_t retry = 0; retry < DXL_PING_RETRY; retry++) {
            if (dxl.ping(DXL_IDS[i])) { legIds[legCount++] = DXL_IDS[i]; break; }
        }
    }
    if (legCount == 0) {
        Serial.println("No DYNAMIXEL found");
        M5.Display.println("No servos");
        return;
    }
    for (uint8_t i = 0; i < legCount; i++) {
        Serial.printf("DYNAMIXEL id=%u model=%u\n", legIds[i], dxl.getModelNumber(legIds[i]));
    }
    M5.Display.printf("Servos: %u\n", legCount);
    M5.Display.printf("A:run B:%d C:zero\n", (int)HOME_DEG);

    setMode(OP_VELOCITY);
    for (uint8_t i = 0; i < legCount; i++) dxl.setGoalVelocity(legIds[i], 0, UNIT_RPM);
}

// A ボタンで回転／停止をトグルする。両脚とも同じ向き・同じ速度で回す
static void toggleSpin() {
    if (legCount == 0) return;
    spinning = !spinning;
    setMode(OP_VELOCITY);  // 連続回転させるだけなので位置ではなく速度で回す
    for (uint8_t i = 0; i < legCount; i++) {
        dxl.setGoalVelocity(legIds[i], spinning ? SPIN_RPM : 0, UNIT_RPM);
    }
    Serial.println(spinning ? "spin: on" : "spin: off");
}

// 両脚を指定したクランク角へ動かして保持する。回転は止める
static void goCrank(float deg) {
    if (legCount == 0) return;
    spinning = false;
    for (uint8_t i = 0; i < legCount; i++) dxl.setGoalVelocity(legIds[i], 0, UNIT_RPM);

    // 現在角を読むのはモードを移した後。速度モードでは多回転ぶんの値が当てにならない
    setMode(OP_EXTENDED_POSITION);
    for (uint8_t i = 0; i < legCount; i++) {
        float present = dxl.getPresentPosition(legIds[i], UNIT_DEGREE);
        // 較正した原点から見て deg になる位置へ。近い側に回るので最大でも半回転
        float goal = present + wrapDeg(deg - crankDeg(i, present));
        dxl.setGoalPosition(legIds[i], goal, UNIT_DEGREE);
        Serial.printf("id=%u goto: crank %.1f -> %.1f deg\n",
                      legIds[i], crankDeg(i, present), deg);
    }
}

// B ボタンはホーム角へ
static void goHome() { goCrank(HOME_DEG); }

// C ボタン: クランク原点の較正。
// 1回目でトルクを抜いて手で回せるようにし、CAD組立姿勢に合わせて2回目を押すと
// その角度を原点として NVS に保存する。方策はこの原点を基準に学習されている
static void toggleCalibration() {
    if (legCount == 0) return;
    calibrating = !calibrating;

    if (calibrating) {
        spinning = false;
        // setMode は最後にトルクを入れる。その瞬間に古い目標へ飛ばないよう、
        // 先に目標を現在位置へ置いてから切り替える
        for (uint8_t i = 0; i < legCount; i++) {
            dxl.setGoalPosition(legIds[i],
                                dxl.getPresentPosition(legIds[i], UNIT_DEGREE),
                                UNIT_DEGREE);
        }
        setMode(OP_EXTENDED_POSITION);  // 位置を読む土俵に揃えてからトルクを抜く
        for (uint8_t i = 0; i < legCount; i++) dxl.torqueOff(legIds[i]);
        Serial.println("calibration: torque off, set the CAD assembly pose");
        return;
    }

    for (uint8_t i = 0; i < legCount; i++) {
        float present = dxl.getPresentPosition(legIds[i], UNIT_DEGREE);
        // いま作った姿勢が CALIB_POSE_DEG である、として原点を逆算する
        legZero[i] = present - CALIB_POSE_DEG;
        // トルクを入れた瞬間に飛ばないよう、目標は「いまの位置」。ここに legZero を
        // 渡すと CALIB_POSE_DEG ぶん離れた場所が目標になり、脚が 280 度回り出す。
        // 直前に方策を走らせているとプロファイルが切れていて、全速で回る
        dxl.setGoalPosition(legIds[i], present, UNIT_DEGREE);
        dxl.torqueOn(legIds[i]);
        Serial.printf("calibration: id=%u zero = %.1f deg (pose = %.1f)\n",
                      legIds[i], legZero[i], CALIB_POSE_DEG);
    }
    saveZeros();
}

// --- アニメーション ---

// 目の開き具合(0.0〜1.0)を返す。まばたきの開始判定もここで行う
static float eyeOpen(uint32_t now) {
    if (now >= blinkAt) {
        blinkEnd = now + BLINK_MS;
        blinkAt  = blinkEnd + random(BLINK_MIN_MS, BLINK_MAX_MS);
    }
    if (now >= blinkEnd) return 1.0f;
    // 閉じ→開きを1本の三角波で表す（p=0.5 で閉じきる）
    float p = 1.0f - (float)(blinkEnd - now) / BLINK_MS;
    return BLINK_OPEN + (1.0f - BLINK_OPEN) * fabsf(p * 2.0f - 1.0f);
}

// 視線のゆらぎを更新する。サッケードの開始判定もここで行う
static void updateGaze(uint32_t now) {
    if (now >= gazeAt) {
        gazeFromX = gazeX;
        gazeFromY = gazeY;
        gazeToX   = random(-GAZE_RANGE_X, GAZE_RANGE_X + 1);
        gazeToY   = random(-GAZE_RANGE_Y, GAZE_RANGE_Y + 1);
        gazeStart = now;
        gazeAt    = now + SACCADE_MS + random(SACCADE_MIN_MS, SACCADE_MAX_MS);
    }
    uint32_t t = now - gazeStart;
    float p = (t >= SACCADE_MS) ? 1.0f : (float)t / SACCADE_MS;
    p = p * p * (3.0f - 2.0f * p);  // smoothstep で動き出しと止まりを滑らかにする
    gazeX = gazeFromX + (int)((gazeToX - gazeFromX) * p);
    gazeY = gazeFromY + (int)((gazeToY - gazeFromY) * p);
}

// --- 描画 ---

// 1つの目を描く。open はまばたきによる縦の潰れ具合
static void drawEye(int cx, int cy, float open) {
    int h = max(4, (int)(EYE_H * open));
    int r = min(EYE_R, min(EYE_W, h) / 2);
    canvas.fillSmoothRoundRect(cx - EYE_W / 2, cy - h / 2, EYE_W, h, r, COLOR_EYE);
}

static void drawFace(uint32_t now) {
    float open  = eyeOpen(now);
    int   drift = (int)(DRIFT_PX * sinf(now * (2.0f * (float)M_PI / DRIFT_PERIOD_MS)));
    int   half  = (EYE_GAP + EYE_W) / 2;  // 画面中央から各目の中心までの距離

    updateGaze(now);
    int cx = SCREEN_W / 2 + gazeX;
    int cy = EYE_CY + gazeY + drift;

    canvas.fillSprite(COLOR_BG);
    drawEye(cx - half, cy, open);
    drawEye(cx + half, cy, open);

    if (policyRunning) {
        canvas.setTextSize(2);
        canvas.setTextColor(COLOR_LABEL);
        canvas.setTextDatum(bottom_center);
        char line[48];
        snprintf(line, sizeof(line), "%s %+0.2f %+0.2f %luHz",
                 policyDryRun ? "DRY" : "RUN",
                 policyAction[0], policyAction[1], (unsigned long)policyHz);
        canvas.drawString(line, SCREEN_W / 2, SCREEN_H - STATUS_MARGIN);
        canvas.setTextDatum(top_left);
    }
    // サーボが空転していても回っているか分かるよう、状態を出しておく
    if (spinning) {
        canvas.setTextSize(2);
        canvas.setTextColor(COLOR_LABEL);
        canvas.setTextDatum(bottom_center);
        canvas.drawString("SPIN", SCREEN_W / 2, SCREEN_H - STATUS_MARGIN);
        canvas.setTextDatum(top_left);
    }

    canvas.pushSprite(0, 0);
}

// 較正中は顔の代わりにクランク角を出す。CAD組立姿勢に合わせる作業のための画面
static void drawCalibration() {
    canvas.fillSprite(COLOR_BG);
    canvas.setTextSize(3);
    canvas.setTextColor(COLOR_EYE);
    canvas.setCursor(8, 12);
    canvas.println("CALIBRATE");

    canvas.setTextSize(2);
    for (uint8_t i = 0; i < legCount; i++) {
        float present = dxl.getPresentPosition(legIds[i], UNIT_DEGREE);
        canvas.setCursor(8, 70 + i * 28);
        canvas.printf("id%u  crank %6.1f", legIds[i], crankDeg(i, present));
    }

    canvas.setTextColor(COLOR_LABEL);
    canvas.setCursor(8, 150);
    canvas.println("Both tips just");
    canvas.setCursor(8, 175);
    canvas.println("touching floor,");
    canvas.setCursor(8, 200);
    canvas.printf("then C (=%d deg)\n", (int)CALIB_POSE_DEG);
    canvas.pushSprite(0, 0);
}

// --- 方策の実行 (50Hz) ---

// --- 方策実行の記録（Sim2Real の食い違いを測るため）---
//
// 実機で観測と行動をそのまま残し、PC 側で同じ行動をシミュレータに流し込む。
// 同じ入力に対して応答が違えば、モデルのどこが実機と違うかが直接分かる。
// 推測ではなく測定で切り分けるための道具。
static const uint16_t LOG_SAMPLES = 500;        // 50Hz で 10 秒
static float    logObs[LOG_SAMPLES][GORON_OBS];
static float    logAct[LOG_SAMPLES][GORON_ACT];
static uint32_t logT[LOG_SAMPLES];
static volatile uint16_t logCount = 0;
static volatile bool     logging  = false;

static void dumpLog() {
    Serial.printf("L,begin,samples,%u\n", logCount);
    for (uint16_t i = 0; i < logCount; i++) {
        Serial.printf("L,%lu", (unsigned long)logT[i]);
        for (int j = 0; j < GORON_OBS; j++) Serial.printf(",%.4f", logObs[i][j]);
        for (int j = 0; j < GORON_ACT; j++) Serial.printf(",%.4f", logAct[i][j]);
        Serial.println();
    }
    Serial.println("L,end");
}

// 観測を組み立てる。並びはエクスポートしたヘッダの冒頭の表に従う
static void buildObs(float obs[GORON_OBS], float crank[DXL_COUNT]) {
    float a[3], g[3];
    M5.Imu.update();
    M5.Imu.getAccel(&a[0], &a[1], &a[2]);   // [g]、静止時は上方向を指す
    M5.Imu.getGyro(&g[0], &g[1], &g[2]);    // [deg/s]

    // IMU 軸 -> ボディ座標系。較正の残差 4.6 度ぶんもここで入る
    for (int i = 0; i < 3; i++) {
        float up = 0.0f, w = 0.0f;
        for (int j = 0; j < 3; j++) {
            up += GORON_IMU_TO_BODY[i][j] * a[j];
            w  += GORON_IMU_TO_BODY[i][j] * g[j];
        }
        obs[i]     = up;                       // [0:3] 重力方向（＝上方向）
        obs[3 + i] = w * (float)M_PI / 180.0f;  // [3:6] 角速度 [rad/s]
    }
    for (int i = 0; i < 3; i++) { lastImu[i] = a[i]; lastImu[3 + i] = g[i]; }

    for (uint8_t i = 0; i < legCount; i++) {
        float present = dxl.getPresentPosition(legIds[i], UNIT_DEGREE);
        crank[i] = present;
        // 方策が学習した原点へ合わせる。crawl/selfright は 0、forward は 240
        float q = (crankDeg(i, present) - GORON_CRANK_ZERO_DEG) * (float)M_PI / 180.0f;
        obs[6 + i] = sinf(q);
        obs[8 + i] = cosf(q);
        // 速度は 0.229 rpm 単位。無負荷速度で正規化する
        lastRaw[i] = present; lastCrank[i] = crankDeg(i, present);
        float vel = dxl.getPresentVelocity(legIds[i], UNIT_RPM) * 2.0f * (float)M_PI / 60.0f;
        obs[10 + i] = vel / GORON_NO_LOAD_SPEED;
        // トルクは電流から。全開PWMの実測電流を失速トルクに対応づけている
        float cur = (float)(int16_t)dxl.readControlTableItem(PRESENT_CURRENT, legIds[i]);
        obs[12 + i] = (cur / DXL_SAT_CURRENT_MA);
    }
}

static void stopPolicy(const char* why) {
    policyRunning = false;
    logging = false;
    for (uint8_t i = 0; i < legCount; i++) {
        dxl.setGoalPosition(legIds[i], dxl.getPresentPosition(legIds[i], UNIT_DEGREE),
                            UNIT_DEGREE);
    }
    Serial.printf("policy: stopped (%s)\n", why);
}

static void startPolicy(bool dry = false) {
    policyDryRun = dry;
    if (legCount < DXL_COUNT) {
        Serial.println("policy: needs both servos");
        return;
    }
    // 較正中はトルクが抜けている。そのまま走らせると、方策は計算も指令もするのに
    // 脚は一切動かず、記録には「速度も電流もゼロ」だけが残る。いちばん気づきにくい
    // 失敗の仕方なので、拒否する
    if (calibrating) {
        Serial.println("policy: still calibrating -- press C to finish first");
        return;
    }
    setMode(OP_EXTENDED_POSITION);
    // setMode はモードが変わらなければ何もしない。トルクだけは毎回入れ直す
    for (uint8_t i = 0; i < legCount; i++) {
        dxl.setGoalPosition(legIds[i], dxl.getPresentPosition(legIds[i], UNIT_DEGREE),
                            UNIT_DEGREE);
        dxl.torqueOn(legIds[i]);
    }
    for (uint8_t i = 0; i < legCount; i++) {
        // プロファイルを切る。入れるとサーボ同定と違う条件になる
        dxl.writeControlTableItem(PROFILE_VELOCITY, legIds[i], 0);
        dxl.writeControlTableItem(PROFILE_ACCELERATION, legIds[i], 0);
        policyTarget[i] = dxl.getPresentPosition(legIds[i], UNIT_DEGREE);
        dxl.setGoalPosition(legIds[i], policyTarget[i], UNIT_DEGREE);
    }
    legMode = 0xFF;          // プロファイルを触ったので次の setMode で入れ直させる
    policyLateUs = 0;
    policyRunning = true;
    // トルクを入れた直後に読み返すと反映前の値を拾うことがある。表示が当てに
    // ならないと確認の意味がなくなるので、少し置いてから読む
    delay(20);
    int torque = 0;
    for (uint8_t i = 0; i < legCount; i++) {
        torque += (int)dxl.readControlTableItem(TORQUE_ENABLE, legIds[i]);
    }
    Serial.printf("policy: started (%s, %d Hz, torque %d/%u)%s\n",
                  GORON_POLICY, GORON_CONTROL_HZ, torque, legCount,
                  dry ? " DRY RUN - servos will not move" : "");
}

static void policyStepOnce();


// Core1 で 50Hz を刻む。vTaskDelayUntil は周期の起点を保つので、
// 1回遅れても次で取り返し、平均周期がずれない
static void policyTask(void*) {
    const TickType_t period = pdMS_TO_TICKS(1000 / GORON_CONTROL_HZ);
    TickType_t last = xTaskGetTickCount();
    uint32_t count = 0, mark = millis();
    for (;;) {
        if (!policyRunning) {
            vTaskDelay(pdMS_TO_TICKS(20));
            last = xTaskGetTickCount();
            policyHz = 0;
            continue;
        }
        uint32_t t0 = micros();
        policyStepOnce();
        uint32_t took = micros() - t0;
        if (took > policyLateUs) policyLateUs = took;   // 1周期ぶんの処理時間
        if (++count >= GORON_CONTROL_HZ) {
            uint32_t now = millis();
            policyHz = count * 1000 / (now - mark);
            count = 0; mark = now;
        }
        vTaskDelayUntil(&last, period);
    }
}
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
void loop() {
    M5.update();

    // フレーム待ちより先に見る。押した瞬間を取りこぼさないため。
    // 較正中は手で脚を動かしている最中なので、動かす操作は受け付けない。
    // A は実機運用の主操作なので方策の起動/停止に割り当て、試運転用の連続回転は
    // シリアルの "W" に移した
    if (M5.BtnA.wasPressed() && !calibrating) {
        policyRunning ? stopPolicy("button") : startPolicy();
    }
    if (M5.BtnB.wasPressed() && !calibrating) {
        if (policyRunning) stopPolicy("home");
        goHome();
    }
    if (M5.BtnC.wasPressed()) {
        if (policyRunning) stopPolicy("calibration");
        toggleCalibration();
    }

    // 制御は Core1 の policyTask が回している。ここでは何もしない

    handleSerialCommand();

    uint32_t now = millis();
    static uint32_t nextTelem = 0;
    // 方策実行中も送る。値は制御ループの写しなので、バスにも制御周期にも
    // 影響しない（scripts/mirror で走行中の姿勢を見るため）
    if (now >= nextTelem) {
        nextTelem = now + TELEM_MS;
        sendTelemetry();
    }

    static uint32_t nextFrame = 0;
    if (now < nextFrame) return;
    nextFrame = now + FRAME_MS;

    if (calibrating) drawCalibration();
    else             drawFace(now);
}

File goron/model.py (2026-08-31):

"""MJCF builder for the two-leg robot.

Topology (NOT the serial chain of `poco`):

        torso (M5Stack + battery, free joint)
       /                              \\
   hip_left (hinge, axis = Y)    hip_right (hinge, axis = Y)
   continuous rotation           continuous rotation

The legs hang off the left and right sides of the torso (at +/-Y) but *swing in
the sagittal plane*: the hinge axes are parallel to the torso's lateral (Y)
axis, so each leg sweeps fore and aft. Both hips rotate **continuously through
360 degrees** -- they are cranks, not limited joints. This is the RHex layout,
reduced to two legs.

Consequences that drive the whole design:

* Both legs cranking together produces a **pitch** torque, so self-righting is
  an end-over-end somersault about Y, not a roll. The torso dimension that sets
  the difficulty is therefore `torso_len` (X), not `torso_width`.
* No left/right mirroring: both hips turn the same way about +Y, so
  `ctrl = [+a, +a]` cranks the legs in phase (pitch / hopping) and
  `ctrl = [+a, -a]` cranks them in anti-phase (yaw / scissoring).
* The hips must sit **outboard of the torso** (`hip_y_gap`), otherwise a leg
  cannot pass the torso and 360 degree rotation is impossible.

Hardware modelled
-----------------
* Servo: **Dynamixel XL330-M288-T**. 288.4:1, 12-bit absolute encoder,
  0.52 N.m stall / 103 rpm no-load at 5.0 V (0.42 N.m / 76 rpm at 3.7 V), 18 g.
  Driven in **Extended Position Control Mode** (+/-256 rev), which is what makes
  continuous rotation *and* absolute angle feedback available at the same time.
* Controller: **M5Stack Core-series**, 54 x 54 x 16 mm, 6-axis IMU on board.
  `board_mass` defaults to the CoreS3's 73.3 g (battery included); a Core2 is
  about 52 g.

The 288:1 gearbox matters more than it looks: reflected rotor inertia is
`ratio^2 * I_rotor`, which lands around 8e-4 kg.m^2 -- roughly fifty times the
inertia of the leg itself. It dominates the swing dynamics, so it is modelled
explicitly as joint `armature` rather than ignored.
"""

from __future__ import annotations

import math
import dataclasses
from dataclasses import asdict, dataclass, field, replace
from pathlib import Path
from typing import Literal

MODELS_DIR = Path(__file__).resolve().parent.parent / "models"


@dataclass(frozen=True)
class RobotParams:
    """Every geometric / actuator quantity worth sweeping.

    Lengths are metres, angles radians, masses kilograms, torques N.m.
    """

    # --- which plane the legs swing in -------------------------------------
    swing: Literal["sagittal", "lateral"] = "sagittal"

    # --- torso = the M5Stack controller ------------------------------------
    torso_len: float = 0.054      # X, fore/aft -- the tipping dimension
    torso_width: float = 0.054    # Y, lateral
    torso_height: float = 0.016   # Z
    board_mass: float = 0.0733    # M5Stack CoreS3 incl. its 500 mAh battery
    extra_mass: float = 0.020     # frame, wiring, fasteners

    # --- legs --------------------------------------------------------------
    # "spiral" reproduces the printed leg measured off the STL: a hub disc with
    # an Archimedean arm winding out from it. `bar` and `c_leg` are the earlier
    # study shapes, kept so the comparison stays reproducible.
    # "mesh" uses the convex-decomposed printed leg from hardware/stl/wedges,
    # produced by scripts/split_leg.py. It is the highest-fidelity option and
    # the slowest; "spiral" is its primitive-geometry stand-in.
    leg_shape: Literal["bar", "c_leg", "spiral", "mesh"] = "bar"
    wedge_dir: Path = MODELS_DIR.parent / "hardware" / "stl" / "wedges"
    # Rotation applied to the mesh leg about its hinge, to line the printed
    # part's zero angle up with the primitive shapes' convention. Without it a
    # policy trained on a primitive reads its own crank-angle observation
    # against a leg pointing somewhere else entirely.
    leg_phase: float = 0.0
    # Draw the printed parts on top of the collision primitives. Visual only:
    # the geoms carry no mass and no contact, so the physics is byte-identical
    # with and without it. For comparing the model against the real robot.
    visual_stl: bool = False
    # Spiral parameters, all measured from hardware/stl/leg_left.stl.
    hub_radius: float = 0.018
    spiral_r0: float = 0.019      # arm radius where it leaves the hub
    spiral_sweep: float = math.radians(120.0)
    spiral_thickness: float = 0.005   # half the arm's radial width
    leg_length: float = 0.050     # hip to foot (bar) / hip to tip (c_leg)
    leg_radius: float = 0.004
    leg_mass: float = 0.008
    foot_radius: float = 0.006
    foot_mass: float = 0.003
    c_leg_segments: int = 6
    c_leg_sweep: float = math.pi  #半円

    # --- hip placement -----------------------------------------------------
    hip_x_frac: float = 0.0       # 0 = mid-length, +1 = nose
    # +1 = top plate. The XL330 case (26 mm) is *taller* than the M5Stack
    # (16 mm), so mounting the servos at mid-height leaves them protruding
    # 5 mm below the belly -- the robot then rests on its servo cases and the
    # belly never reaches the floor. See `servo_clears_belly`.
    hip_z_frac: float = 1.0
    # Outboard gap between the torso side wall and the hip axis. Must be big
    # enough that the rotating leg clears the torso.
    hip_y_gap: float = 0.012

    # --- servo: Dynamixel XL330-M288-T -------------------------------------
    servo_mass: float = 0.018
    servo_size: tuple[float, float, float] = (0.020, 0.034, 0.026)
    servo_stall_torque: float = 0.52    # N.m at 5.0 V
    servo_no_load_speed: float = 10.79  # rad/s (103 rpm) at 5.0 V
    servo_gear_ratio: float = 288.4
    servo_rotor_inertia: float = 1.0e-8  # kg.m^2, estimated -- identify on HW
    servo_kp: float = 5.0               # N.m/rad, internal position loop
    # Viscous damping at the joint. This used to be derived as stall torque over
    # no-load speed, but that quantity describes the motor's *electrical*
    # behaviour, not mechanical drag, and measurement on the robot showed the
    # real viscous term is far smaller. The old value is kept as the default so
    # existing runs reproduce; identification overrides it.
    joint_damping: float = 0.0482       # = 0.52 / 10.79, the old derivation
    # Coulomb friction in the gearbox, N.m. Not a refinement: with torque off
    # the leg does not fall at all, so dry friction exceeds the 1.5e-3 N.m that
    # gravity applies to it. A viscous-only joint cannot reproduce that.
    joint_frictionloss: float = 0.0

    # --- contact -----------------------------------------------------------
    floor_friction: float = 1.0
    foot_friction: float = 1.2

    timestep: float = 0.002

    def with_(self, **kwargs) -> "RobotParams":
        return replace(self, **kwargs)

    def to_dict(self) -> dict:
        """Serialisable form, for recording alongside a training run.
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

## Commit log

2026-08-16 Set up the uv project skeleton
    Bare scaffolding only: dependency pins and the ignore rules. The ignore list
    covers the three things this project generates in bulk and should never track
    -- MJCF written out for viewing, training runs, and PlatformIO build output.
2026-08-30 2脚クランクロボットの Sim2Real パイプライン (#1)
    * Add the MuJoCo model, environment and task definitions
    The robot is a torso with two legs that swing in the sagittal plane and rotate
    continuously through 360 degrees -- an RHex layout cut down to two cranks.
    `RobotParams` keeps every dimension and servo figure adjustable so geometry can
    be swept rather than guessed, and `build_mjcf` generates the model in memory;
    nothing reads an XML file back.
    Three modelling choices carry most of the weight:
    * Crank angle enters the observation as sin/cos. The joints turn without limit,
    so a raw angle would jump at every wrap and grow without bound.
    * The action is an *increment* to t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
    [all.stl, bat.stl, body_bottom.stl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]
2026-08-31 立つタスクと、実機で分かったこと (#3)
    * update gitignore
    * Observe the accelerometer, not the attitude
    obs[0:3] was the torso's up axis: a unit vector by construction. The real IMU
    measures specific force, which is gravity plus whatever the body is doing.
    They agree at rest and nowhere else -- ten seconds of the robot trying to
    stand gives 0.40 to 3.66 g, more than 20% off unit length a quarter of the
    time. The policy met inputs it had never seen exactly when it was working
    hardest, and could only flap its legs.
    The model had declared an accelerometer sensor all along and nothing read it.
    What kept the mistake invisible was a test asserting the vector always has
    unit lengt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
    [main.cpp, model.py]
2026-08-31 Sim2Real 実践帳（教材）を追加 (#2)
    * Add the sim2real handbook
    A single self-contained page covering the whole pipeline: writing a MuJoCo
    model, what reinforcement learning is asking for, identifying the real
    machine, and getting a policy onto the microcontroller.
    Every number in it comes from this repository -- the step-response figure is
    the real fit (17.0% to 2.5% trajectory error), the friction sweep is the real
    measurement, the masses are the weighed ones. Generic tutorials are easy to
    find; what is hard to find is what the mistakes look like from the inside, so
    the seven traps are first-class content and each carries the symptom, the
    cause, and how it was actually caught. S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
